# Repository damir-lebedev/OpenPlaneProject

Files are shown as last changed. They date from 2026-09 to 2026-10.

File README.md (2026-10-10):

<!-- i18n-bar:start -->
  <p align="center">
    🇷🇺 <b>Читать на русском</b>
    &nbsp;·&nbsp;
    <a href="docs/i18n/en/README.md">🇬🇧 Read this in English</a>
    &nbsp;·&nbsp;
    <a href="docs/i18n/zh-CN/README.md">🇨🇳 阅读中文版</a>
    &nbsp;·&nbsp;
    <a href="docs/i18n/es/README.md">🇪🇸 Lee esto en español</a>
  </p>
  <p align="center">
    <a href="docs/i18n/hi/README.md">🇮🇳 हिन्दी में पढ़ें</a>
    &nbsp;·&nbsp;
    <a href="docs/i18n/ar/README.md">🇸🇦 اقرأ بالعربية</a>
    &nbsp;·&nbsp;
    <a href="docs/i18n/pt-BR/README.md">🇧🇷 Leia em português</a>
    &nbsp;·&nbsp;
    <a href="docs/i18n/fr/README.md">🇫🇷 Lire en français</a>
  </p>
  <p align="center">
    <a href="docs/i18n/de/README.md">🇩🇪 Auf Deutsch lesen</a>
    &nbsp;·&nbsp;
    <a href="docs/i18n/ja/README.md">🇯🇵 日本語で読む</a>
    &nbsp;·&nbsp;
    <a href="docs/i18n/ko/README.md">🇰🇷 한국어로 읽기</a>
    &nbsp;·&nbsp;
    <a href="docs/i18n/sv/README.md">🇸🇪 Läs på svenska</a>
  </p>
<!-- i18n-bar:end -->

<p align="center">
  OpenPlane — открытый автопилот для самолётов
</p>

<p align="center">
  
  
  
  <br>
  
  
  
  
</p>

<h3 align="center">Выключили пульт — самолёт сам вернулся домой и кружит над вами.</h3>
<p align="center">Это не мультфильм: <b>вся прошивка</b> ведёт модель самолёта в замкнутом контуре — те же байты iBUS на входе, тот же ШИМ на выходе.</p>

<p align="center">
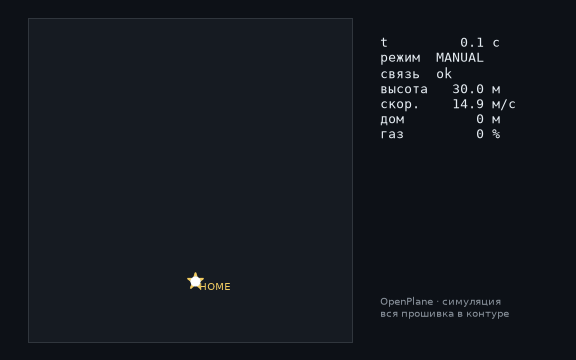
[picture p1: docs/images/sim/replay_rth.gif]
Потеря связи: самолёт сам возвращается домой и кружит
  
</p>

---

## ⚡ За 30 секунд

| | |
|---|---|
| **Что это** | Открытый полётный контроллер и автопилот для радиоуправляемых самолётов. Основная плата — STM32H743 (класс плат Pixhawk): на плате DevEBox прошивка **уже запущена и управляется с пульта** — [есть видео](#-stm32h743-ожила-на-плате), сейчас подключаются датчики. Прежняя основа — ESP32-S3 за ~$10, на ней пройден стенд со всеми датчиками. |
| **Что умеет** | 12 режимов полёта — от стабилизации до возврата домой, кругов по GPS, запуска с руки, автопосадки и **парения в термиках**. Трубка Пито из двух дешёвых барометров. Телеметрия MAVLink в QGroundControl и Mission Planner. |
| **Главная фишка** | Любой тумблер или крутилка пульта = любая функция. **Одна строка** в `Controls.h` — и SwD уже не RTH, а сброс груза. |
| **Почему можно верить** | 387 автотестов (плюс 9 на самой плате с настоящей SD-картой), 98 % кода под тестами, 24 сборки «плата × датчики» без единого предупреждения, замкнутые симуляции каждого режима. |
| **Честно** | В воздухе пока был ручной режим (первый прототип). STM32H743 пока проверена на столе, без датчиков. Автопилот проверен на стенде, тестами и симуляциями и ждёт лётных испытаний — [статус ниже](#-честный-статус). |

---

## 🎛️ Тумблер = функция. Одна строка.

```cpp
// include/config/Controls.h
constexpr Binding BINDINGS[] = {
    Bind::modes  (Channels::SWC, MODE_MANUAL, MODE_STABILIZE, MODE_AUTO_TAKEOFF),
    Bind::feature(Channels::SWB, Feature::FLAPS),
    Bind::mode   (Channels::SWD, MODE_RTH),              // домой, пока включён
    Bind::knob   (Channels::VRA, Knob::STAB_GAIN),       // "мягче / жёстче" прямо в полёте
    Bind::knob   (Channels::VRB, Knob::CRUISE_SPEED),
};
```

Хотите на SwD парение в термиках вместо RTH? `Bind::mode(Channels::SWD, MODE_SOARING)`. Сброс груза на SwB? `Bind::feature(Channels::SWB, Feature::PAYLOAD_DROP)`. Ошиблись — например, повесили два режима на один тумблер или заняли стик — **сборка не пройдёт**: таблицу проверяет компилятор (`static_assert`). При включении борт сам печатает, что на каком тумблере.

**12 режимов · 10 функций · 7 крутилок** — всё с примерами в [справочнике автопилота](docs/AUTOPILOT_GUIDE.md).

---

## ✈️ Что умеет автопилот

| | Режим | Суть |
|---|---|---|
| 🕹️ | **MANUAL** | рули = стики, как без полётника |
| 🧭 | **STABILIZE** | стик задаёт угол; отпустил — самолёт сам в горизонте |
| 📏 | **ALT_HOLD** | + держит высоту по барометру |
| 🌀 | **ACRO** | стик задаёт скорость вращения — для фигур |
| 🛣️ | **CRUISE** | курс, высота и скорость держатся сами; стики только поправляют |
| ⭕ | **LOITER** | круги над точкой по GPS (радиус — крутилкой) |
| 🏠 | **RTH** | домой на 40 м и круги над головой; сам включается при потере связи |
| 🛫 | **AUTO_TAKEOFF** | взлёт с полосы по газу пилота |
| 🤾 | **LAUNCH** | запуск с руки: мотор после броска, набор высоты |
| 🛬 | **AUTO_LAND** | планирование и выравнивание у земли |
| 🦅 | **SOARING** | мотор выключен, находит термики и кружит в них |
| 🆘 | **RESCUE** | «спасите»: крылья ровно, нос вверх — из любой спирали |

Плюс: геозабор, автотриммер «кривого» самолёта, координация разворота, защита от сваливания по трубке Пито, закрылки и воздушный тормоз, сброс груза, стабилизированная камера, пищалка «ищите меня в траве».

---

## 📈 Каждый режим летает — в замкнутом контуре

Не «функция вернула число», а **полёт**: пульт → кадр iBUS → прошивка → ШИМ → отклонения рулей → модель самолёта с подъёмной силой, сваливанием, ветром и термиками → датчики → снова прошивка. 14 таких полётов — часть обычных тестов (`pio test -e native`).

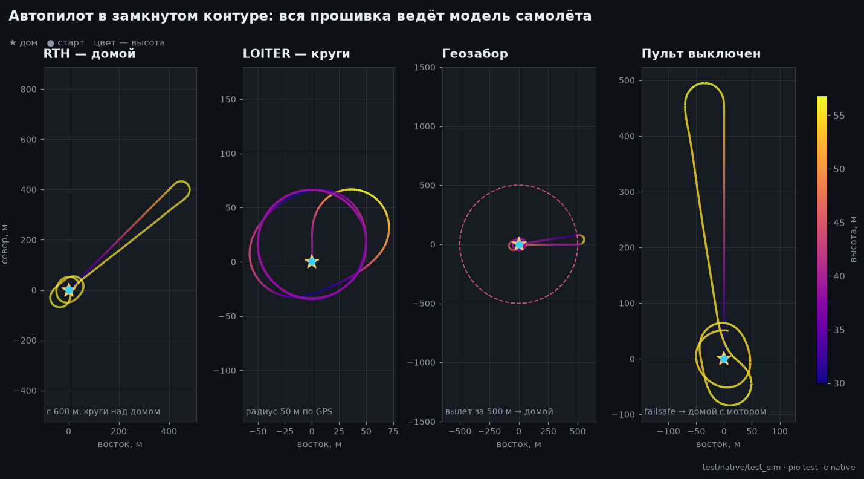
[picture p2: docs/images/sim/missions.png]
RTH, LOITER, геозабор и потеря связи — вид сверху


<table>
  <tr>
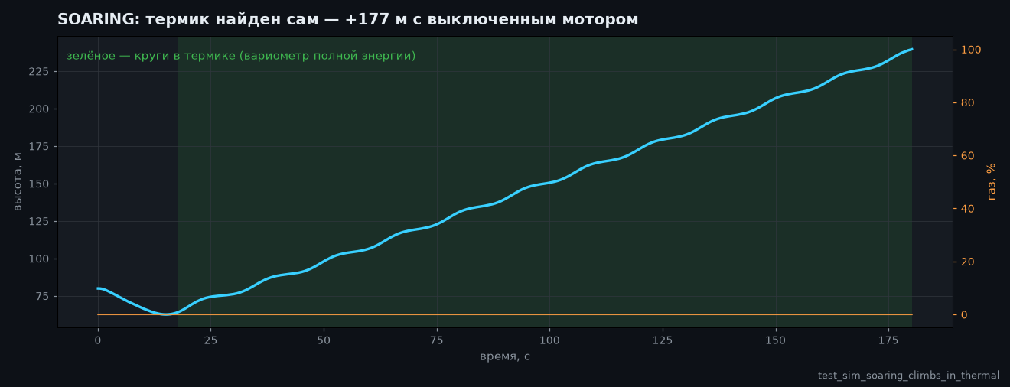
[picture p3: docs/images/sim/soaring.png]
Парение: набор высоты в термике без мотора
    <td width="50%"></td>
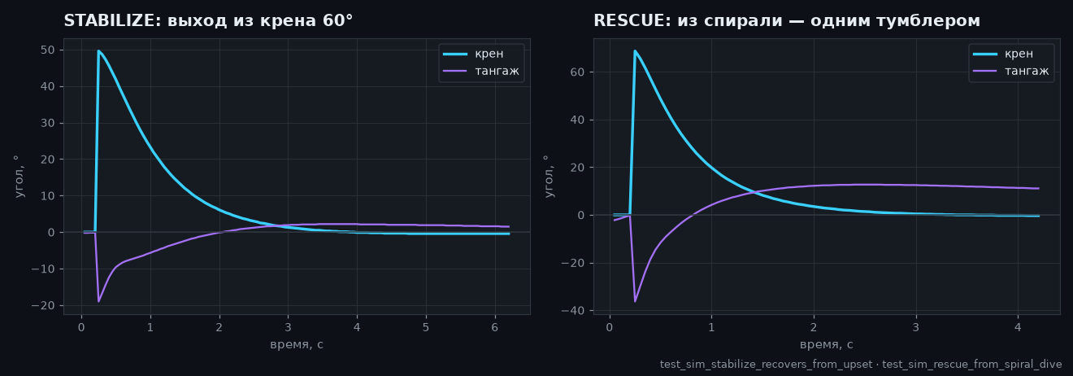
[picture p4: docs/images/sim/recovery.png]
Выход из крена и из спирали
    <td width="50%"></td>
  </tr>
  <tr>
    <td>🦅 Нашёл термик сам и набрал высоту <b>с выключенным мотором</b> — вариометр полной энергии не путает «ручку на себя» с восходящим потоком.</td>
    <td>🆘 Крен 60° — и через секунды горизонт. RESCUE вытаскивает из спирали с креном 70° и носом −40°.</td>
  </tr>
  <tr>
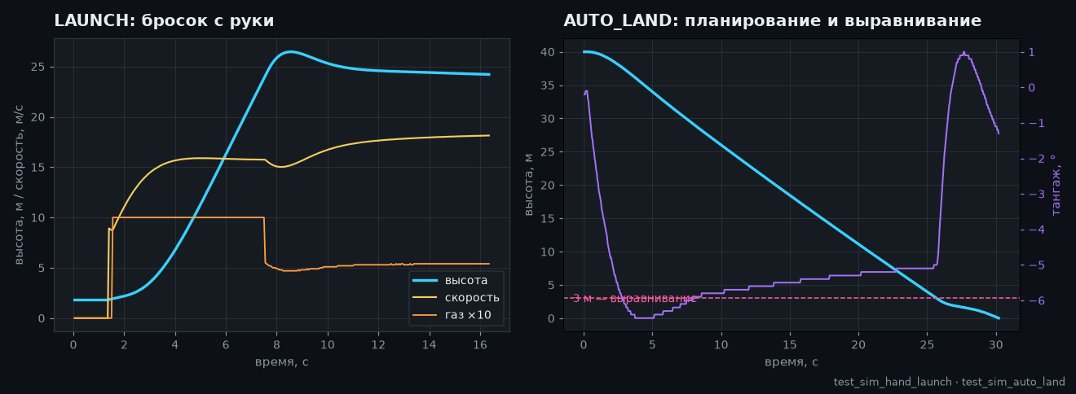
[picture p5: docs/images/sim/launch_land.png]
Запуск с руки и автопосадка
    <td></td>
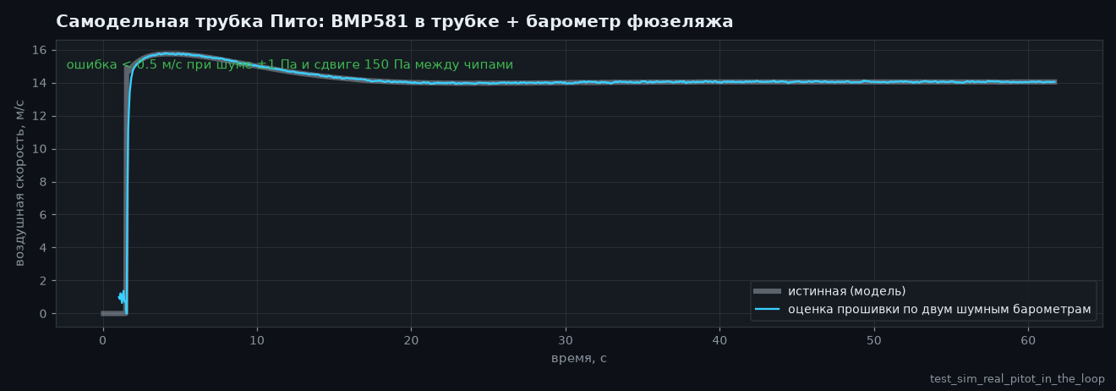
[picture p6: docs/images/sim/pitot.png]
Трубка Пито на двух барометрах
    <td></td>
  </tr>
  <tr>
    <td>🤾 Бросок с руки → мотор только после того, как рука ушла от винта → набор. 🛬 Посадка: планирование и выравнивание на 3 м.</td>
    <td>🌬️ Скорость по трубке из двух <b>шумных</b> барометров со сдвигом 150 Па между чипами — ошибка меньше 0.5 м/с.</td>
  </tr>
</table>

---

## 🌬️ Трубка Пито за копейки

Нормальный датчик воздушной скорости стоит как половина полётника. Здесь — **два барометра**: BMP581 в трубке (полное давление) и основной барометр в фюзеляже (статика). Прошивка сама обнуляет разницу чипов на земле, фильтрует, считает плотность воздуха по высоте и температуре и замечает перепутанные шланги. Что это даёт: CRUISE держит **воздушную** скорость, а не газ; защита от сваливания; честная скорость в телеметрии. Сборка — в [справочнике](docs/AUTOPILOT_GUIDE.md#трубка-пито-своими-руками).

---

## 📡 Наземная станция: браузер или QGroundControl

<table>
  <tr>
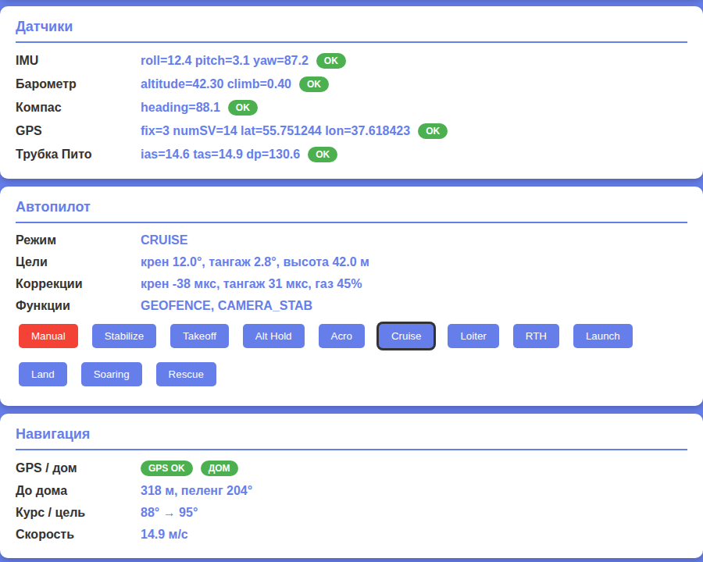
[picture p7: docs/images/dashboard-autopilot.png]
Веб-дашборд: датчики, автопилот, навигация
    <td width="46%"></td>
    <td>
      <b>ESP32 — веб-дашборд прямо с борта.</b> Точка доступа <code>OpenPlane-Debug</code>, адрес <code>192.168.4.1</code>: каналы пульта, выходы, все датчики, режим, навигация, смена режима и ПИД на лету. Без приложений и лишнего железа.<br><br>
      <b>STM32H743 — MAVLink по радиомодему.</b> QGroundControl и Mission Planner видят борт как самолёт ArduPilot: горизонт, карта с домом, скорость по трубке, режимы именами ArduPlane, ПИД из окна параметров, смена режима кнопкой. ARM с земли — нельзя, только тумблером: так безопаснее.<br><br>
      Кадры MAVLink побайтно сверены с эталонной <code>pymavlink</code>.
    </td>
  </tr>
</table>

---

## 📼 Чёрный ящик

Плата пишет каждый полёт: IMU на 500 Гц, углы и решения автопилота, ПИД, все выходы, стики, барометр, компас, GPS, батарея и события — с ARM и газа до посадки, с 10 секундами до старта. **ESP32-S3** — во встроенный флеш (13.9 МБ, около 11 минут), **STM32H743** — на SD-карту (64 МБ — около часа; карта остаётся обычной FAT32, прошивка пишет в заранее созданный файл `BLACKBOX.BIN`). Стирание — только на земле. После полёта `python tools/blackbox.py download` скачивает полёт по USB и раскладывает в CSV; с SD-карты полёты разбираются и без платы: `python tools/blackbox.py ring E:/BLACKBOX.BIN`. Подробно — [BLACKBOX.md](docs/BLACKBOX.md).

---

## 🔩 Железо: одна прошивка — четыре платы, двенадцать датчиков

| Плата | Статус | Что проверено |
|---|---|---|
| **STM32H743VIT6** | ✅ основная · 🔧 DevEBox, датчики подключаются + 🧪 тесты | на плате: загрузка, консоль по USB, **SD-карта и чёрный ящик** (тесты на плате), **приём iBUS, ARM и управление сервами и мотором с пульта** (запуск на видео); на ПК — вся прошивка: задачи FreeRTOS, флеш, MAVLink, I2C и SPI. Датчики к плате ещё не подключали |
| **ESP32-S3 N16R8** | ✅ прежняя основная, на стенде | все датчики, сервы, iBUS, OLED, дашборд вживую; прошивка целиком — в тестах |
| **ESP32 38-pin** | 🧪 тесты | прошивка целиком в тестах с набором ICM-45686 |
| **ESP32-C3 SuperMini** | ✈️ летал (ручной) | первый прототип; сборка всех наборов |

| Датчик | Что это | Шины |
|---|---|---|
| **LSM6DSV** + **QMC6309** | IMU + компас (модуль) | I2C / SPI |
| **ICM-45686** + **QMC6309** | IMU + компас (замена) | I2C / SPI |
| **SPL06-001** | барометр фюзеляжа | I2C / SPI |
| **BMP581** | основной барометр и барометр в трубке Пито | I2C / SPI |
| MPU6050/6500, ICM-42688, BMP388, BME280, QMC5883P/L | стендовые и прежние | I2C / SPI |
| **u-blox M10** | GPS, 10 Гц, UBX | UART |

Датчик меняется одной строкой (`SENSOR_KIT_LSM6DSV_PITOT`), плата — одним флагом сборки. Все 4 платы × 6 наборов датчиков собираются без предупреждений: [`tools/build_matrix.sh`](tools/build_matrix.sh).

<table>
  <tr>
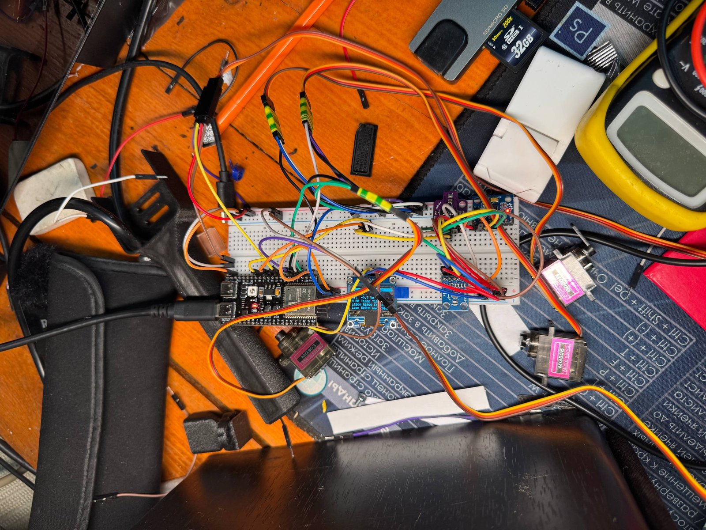
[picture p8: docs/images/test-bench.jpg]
Стенд: ESP32-S3 со всеми датчиками
    <td width="50%"></td>
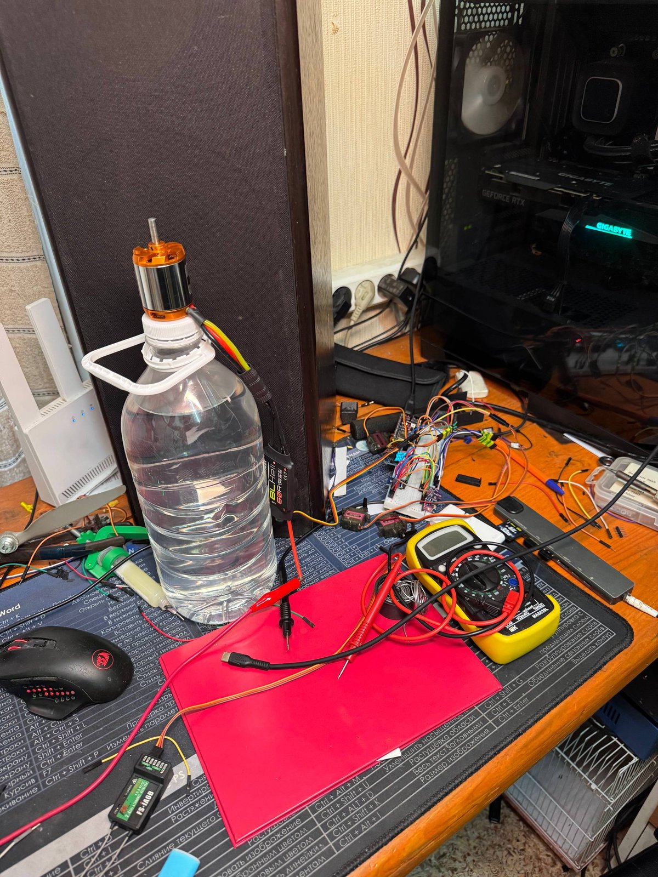
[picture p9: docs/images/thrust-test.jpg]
Тест тяги мотора
    <td width="50%"></td>
  </tr>
  <tr>
    <td>Стенд на ESP32-S3: IMU, барометр, компас, OLED, сервы, приёмник.</td>
    <td>Тест винтомоторной группы.</td>
  </tr>
</table>

### 🎥 STM32H743 ожила на плате

Прошивка для STM32H743 запущена на плате DevEBox **без единого датчика** и управляется с обычного пульта: приёмник по iBUS, ARM, сервы и мотор отвечают на стики и тумблеры в ручном режиме. Весь запуск снят на видео.

▶️ **[Смотреть запуск на видео](https://t.me/lisnmylife/420)**

Что это доказывает: тракт «пульт → iBUS → прошивка → ШИМ» работает на настоящем железе, а не только в тестах. Что ещё не доказано: датчики (IMU, барометр, GPS) к этой плате не подключали, поэтому режимы автопилота на ней пока не пробовались.

---

## 🧪 Качество, которое можно проверить

| | |
|---|---|
| **387 автотестов** | модули, драйверы по регистрам чипов, замкнутые полёты, прошивка ESP32 и STM32 **целиком** на ПК; плюс 9 тестов на самой плате STM32 с настоящей SD-картой |
| **98.3 % строк, 87.7 % ветвлений** | покрытие `gcovr`, включая код STM32 |
| **24/24 сборки** | 4 платы × 6 наборов датчиков, `-Wall -Wextra`, ноль предупреждений |
| **0 замечаний** | cppcheck и clang-tidy по всему коду |
| **Эталоны, а не копии кода** | формулы датчиков — по датащитам (Bosch, ST, TDK, Goertek), MAVLink — по pymavlink |

```bash
pio test -e native -e native-stm32   # все тесты, ~1.5 минуты, железо не нужно
```

Подробно — [TESTING.md](docs/TESTING.md).

---

## 🧠 Как устроено

```mermaid
flowchart LR
    RC["Пульт FS-i6<br/>iBUS"] --> SW["PilotSwitches<br/>Controls.h"]
    SENS["IMU · барометры · компас<br/>GPS · трубка Пито"] --> AP
    SW --> AP["Autopilot<br/>12 режимов · навигация<br/>failsafe · геозабор"]
    AP --> FC["FlightController<br/>ARM · микшер · закрылки"]
    FC --> OUT["Сервы · ESC<br/>груз · камера"]
    AP -.-> TLM["Дашборд Wi-Fi<br/>MAVLink · OLED"]
```

- **Header-only C++**, одна единица трансляции, никакой динамической памяти в полётном контуре. Любитель `.h/.cpp`? Для вас — параллельная ветка [`feature/split-headers`](https://github.com/damir-lebedev/OpenPlaneProject/tree/feature/split-headers): генерируется из этой скриптом, прошивка с LTO того же размера.
- **HAL** — единственный слой, знающий MCU: новая плата — это новый `Board`, а не переписанный автопилот.
- **Драйвер датчика не знает шину**: один класс работает по I2C и по SPI.
- **Безопасность — порядком операций**: потеря связи > ARM > режим > газ; ни один режим не протащит газ мимо ARM.

Подробно — [ARCHITECTURE.md](docs/ARCHITECTURE.md).

---

## 🚀 Быстрый старт

```bash
pip install platformio
git clone https://github.com/damir-lebedev/OpenPlaneProject && cd OpenPlaneProject
pio run -e stm32h743-devebox -t upload                    # DevEBox H743: USB DFU, консоль по USB
pio run -e esp32-s3 -t upload && pio device monitor     # ESP32-S3
pio run -e stm32h743 -t upload                            # STM32H743 (ST-Link)
```

DevEBox: на плате нет кнопки BOOT0 — перед первой заливкой соедините пин BT0 с 3V3 и нажмите RST; потом клавиша `D` в консоли сама перезагружает плату в загрузчик ([подробно](docs/DEVELOPER_GUIDE.md#stm32h743)).

В мониторе порта: `h` — меню, `b` — какие чипы видны на шинах, `s` — датчики, `p` — проверка выходов (пропеллер снять!). Дальше — [гайд пилота](docs/PILOT_GUIDE.md).

---

## 🟢 Честный статус

| Что | Где проверено |
|---|---|
| Ручное управление, микшер | ✈️ в полёте (первый прототип, C3) |
| ARM, failsafe, закрылки, сервы, мотор | 🔧 на стенде (S3) |
| STABILIZE | 🔧 на стенде: рули отвечают на наклоны в правильную сторону |
| Датчики стенда (MPU6500, BMP388, QMC5883P), OLED, дашборд | 🔧 на стенде |
| Остальные режимы, навигация, трубка Пито, MAVLink | 🧪 тесты и замкнутые симуляции |
| Новые датчики (LSM6DSV, ICM-45686, QMC6309, SPL06, BMP581) | 🧪 регистровые эмуляторы по датащитам |
| STM32H743: SD-карта, чёрный ящик, консоль по USB | 🔧 на плате DevEBox (тесты на плате) |
| STM32H743: iBUS, ARM, ШИМ на серво и мотор, ручное управление | 🔧 на плате без датчиков, снято на видео |
| STM32H743: датчики (IMU, барометр, компас, GPS) и режимы автопилота | 🧪 вся прошивка на ПК; к плате датчики ещё не подключали |

Модель самолёта в симуляциях упрощённая, коэффициенты — стартовые. Каждый новый режим сначала пробуется на высоте, с пальцем на тумблере MANUAL.

---

## 🗺️ Дорожная карта

- [x] Ручное управление, ARM, failsafe, объектная прошивка, веб-дашборд
- [x] Стенд ESP32-S3 со всеми датчиками — вживую
- [x] 12 режимов, навигация по GPS, RTH при потере связи, геозабор
- [x] Тумблеры и крутилки одной строкой, сброс груза, камера, автотриммер
- [x] Трубка Пито из двух барометров, защита от сваливания
- [x] Новые датчики: LSM6DSV, ICM-45686, QMC6309, SPL06, BMP581
- [x] STM32H743: полная прошивка, MAVLink, настройки во флеше
- [x] Замкнутые симуляции всех режимов, прошивка целиком в тестах
- [x] Чёрный ящик: полёт во флеш (ESP32-S3) и на SD-карту (STM32H743), выгрузка и разбор в CSV
- [x] STM32H743 запущена на плате: пульт → iBUS → сервы и мотор (без датчиков, на видео)
- [ ] STM32H743: подключить датчики и пройти стенд так же, как ESP32-S3
- [ ] Лётные испытания автопилота на новом планере
- [ ] Своя плата полётника ([FC_BOARD.md](docs/FC_BOARD.md)) на STM32H743
- [ ] Полёт по маршрутным точкам, миссии MAVLink
- [ ] Адаптивная обратная связь (заготовка уже проверена в симуляции)
- [ ] Датчик тока и батареи, телеметрия на пульт (iBUS-SENS)
- [ ] Автономная доставка: маршрут → сброс груза → домой

Подробно — [ROADMAP.md](docs/ROADMAP.md).

---

## 💼 Для партнёров и инвесторов

Небольшие самолёты-доставщики и мониторинговые борта — это либо закрытые дорогие платформы, либо разрозненные хобби-проекты. OpenPlane целится в середину: **открытый, проверяемый автопилот на массовом железе**, где каждая функция покрыта тестами и может быть адаптирована под задачу — доставка медикаментов в труднодоступные места, мониторинг полей и лесов, поисковые работы.

Что уже сделано на свои: архитектура, которая переносится между платами без переписывания; автопилот с полным набором режимов; инфраструктура тестов, на которой новые функции появляются быстро и не ломают старые. Что ускорят ресурсы: лётные испытания, своя плата полётника на STM32H743, полёт по маршруту и сброс груза. Куда и зачем — [ROADMAP.md](docs/ROADMAP.md).

---

## 📚 Документация

| Документ | Для кого |
|---|---|
| [AUTOPILOT_GUIDE.md](docs/AUTOPILOT_GUIDE.md) | пилоту: каждый режим, функция и крутилка, как повесить на тумблер, трубка Пито, наземная станция |
| [PILOT_GUIDE.md](docs/PILOT_GUIDE.md) | сборка, распиновка, пульт, failsafe, первый полёт |
| [DEVELOPER_GUIDE.md](docs/DEVELOPER_GUIDE.md) | разработчику: файлы, знаки, API, как добавить датчик, режим, плату |
| [ARCHITECTURE.md](docs/ARCHITECTURE.md) | слои, задачи, такт управления, автоматы |
| [TESTING.md](docs/TESTING.md) | тесты, симуляции, покрытие, анализ |
| [reference/](docs/reference/README.md) | справочник по каждому классу |
| [FC_BOARD.md](docs/FC_BOARD.md) · [ROADMAP.md](docs/ROADMAP.md) | плата полётника · куда движется проект |
| [airframe/](airframe/README.md) | планер Astro-Cargo: проект Fusion 360 и STL для печати, известные недостатки версии v2 |

> **Связанный проект:** [esp32-rc-joystick](https://github.com/damir-lebedev/esp32-rc-joystick) — пульт FS-i6 как USB-джойстик для симулятора на той же ESP32-S3: сначала налетать часы в симуляторе, потом — в поле.

---

## 🤝 Участие

Нужны руки и головы: аэродинамика и авиамоделизм, 3D-печать и прочность, встраиваемый C++, датчики и автопилоты, наземные интерфейсы. Issues и pull request'ы — в ветку `main`; начать — с [DEVELOPER_GUIDE.md](docs/DEVELOPER_GUIDE.md).

## 📜 Лицензия

[OpenPlane License](LICENSE) — лицензия на основе MIT с дополнительными условиями. Код, документацию и файлы модели можно использовать, копировать, менять и продавать, в том числе в коммерческих продуктах. Условия такие:

1. **Укажите автора — Damir Lebedev (Damn / Проклятый).** Имя должно стоять там, где его увидят пользователи вашего продукта: в документации, README или на странице «О проекте». Текст лицензии оставляйте вместе с кодом.
2. **Военное применение запрещено.** Нельзя использовать проект для армий и военизированных организаций, на войне, при создании оружия, боеприпасов, систем доставки и наведения.
3. **Нельзя намеренно вредить людям и имуществу без их предварительного письменного согласия на этот вред.** Свою собственную технику ломать можно, если это никому не угрожает: например, стрелять из пневматического пистолета по собственному дрону. Калечить и убивать людей нельзя.
4. **Соблюдайте технику безопасности и законы** при сборке, испытаниях и полётах.

Если условия нарушены, разрешение на использование прекращается. Из-за запретов на отдельные виды использования это не «открытая» лицензия в понимании OSI: код доступен для чтения, копирования и изменения, но формально проект относится к source-available, а не к open source.

Юридическую силу имеет только английский текст в файле [LICENSE](LICENSE): переводы лицензии на другие языки даны для удобства.

Прошивка управляет летательным аппаратом и не сертифицирована. Всё, что вы с ней делаете, — на ваш страх и риск; автор ответственности не несёт.

```text
OpenPlane © 2026 Damir Lebedev (Damn / Проклятый) — https://github.com/damir-lebedev/OpenPlaneProject
```

<p align="center"><i>Первый прототип сломался в первом же полёте — поэтому здесь всё на виду: код, тесты, проблемы. Собирайте, ломайте, чините вместе с нами.</i></p>

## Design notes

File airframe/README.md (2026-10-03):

# Планер Astro-Cargo: модель и файлы для печати

Здесь лежит сам самолёт: проект в Fusion 360 и STL-файлы для 3D-печати. Электронику и плату полётника описывает [FC_BOARD.md](../docs/FC_BOARD.md), а сборку и первый полёт — [гайд пилота](../docs/PILOT_GUIDE.md).

## Версия модели: v2

В этой папке лежит **Astro-Cargo v2**. Версии v1 в репозитории не будет: первая модель не публикуется, поэтому вторая стала первой выложенной.

- [Проект Fusion 360](fusion360/Astro-Cargo%20v2%20%28Bad%20wheel%20%26%20no%20battery%20mount%29.f3d), 14 МБ;
- [STL-файл для печати](stl/Astro-Cargo%20v2%20%28Bad%20wheel%20%26%20no%20battery%20mount%29.stl), 6 МБ.

Файлы названы так, чтобы по имени было сразу видно, что в этой версии не так (подробности ниже).

> [!WARNING]
> **В v2 найдены критические недостатки конструкции:**
>
> 1. **Слабое крепление шасси к фюзеляжу.** Оно не выдерживает вес самолёта, и фюзеляж рвётся в месте крепления.
> 2. **Нет крепления для ленты-липучки (велкро), которой фиксируется аккумулятор.**
>
> Оба недостатка будут исправлены в следующем прототипе, **Astro-Cargo v3**. Его модель появится в этой папке, как только будет готова. До тех пор не поднимайте v2 в воздух без доработки: усильте крепление шасси и сделайте место под липучку сами.

## Что где лежит

| Папка | Что в ней |
|---|---|
| [`fusion360/`](fusion360/) | Исходный проект: файл `.f3d` (или архив `.f3z`, если в проекте несколько файлов). Из него можно менять размеры и заново выгружать детали |
| [`stl/`](stl/) | Детали, готовые к печати, в формате STL |

## Как называть файлы

- Имена — латиницей, с номером версии. Файлы v2 названы так, чтобы имя говорило о недостатках, но дальше лучше обходиться без пробелов и скобок: `astro-cargo_v3.f3d`, `astro-cargo_v3.stl`. Так на файл проще ссылаться из документации. Если деталей несколько, то каждая лежит в своём файле: `fuselage_v3.stl`, `wing_left_v3.stl`.
- Файлы v3 будут лежать рядом (`astro-cargo_v3.f3d`), а файлы v2 останутся: по ним видно, что именно исправлено.
- Единицы — миллиметры. Если в проекте другие, напишите об этом рядом с файлом.

## Если файл слишком большой

GitHub не принимает файлы тяжелее 100 МБ, а предупреждает уже начиная с 50 МБ. Поэтому перед коммитом проверьте размер файла. Такие файлы кладите не в репозиторий, а:

- в раздел **Releases** на GitHub: файл можно прикрепить к релизу, и он может весить до 2 ГБ;
- в [Git LFS](https://git-lfs.com), если файл должен лежать прямо в репозитории и меняться вместе с кодом;
- на внешний хостинг, а ссылку на него добавьте в этот README.

Файлы `.stl`, `.f3d`, `.f3z`, `.step`, `.stp` и `.3mf` в этой папке git считает бинарными (см. [`.gitattributes`](../.gitattributes)): он не меняет в них переводы строк и не показывает построчные различия.

## Лицензия

Модель распространяется на тех же условиях, что и весь проект: [OpenPlane License](../LICENSE), то есть MIT с обязательным указанием автора, запретом военного применения и запретом умышленного вреда людям и имуществу без их согласия. Печатать, менять и улучшать её можно в этих рамках, но имя автора, Damir Lebedev (Damn / Проклятый), нужно указать.

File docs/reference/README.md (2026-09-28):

# Справочник по классам

Полный перечень классов, структур, перечислений и пространств имён прошивки,
сгруппированный по слоям. Общая картина (слои, потоки, автоматы) — в
[`../ARCHITECTURE.md`](../ARCHITECTURE.md); практические рецепты — в
[`../DEVELOPER_GUIDE.md`](../DEVELOPER_GUIDE.md).

Все пути — от `include/`, кроме `src/`. Все классы header-only (вариант с `.h/.cpp` — ветка `feature/split-headers`).

| Страница | Слой | Что внутри |
|---|---|---|
| [config.md](config.md) | CONFIG | `Config`, `Channels`, `Controls` |
| [hal.md](hal.md) | HAL | `IBoard`, `ServoChannel`, `II2CBus`, `ISpiBus`, `IUartPort`, `IServoOutput`, `IRegisterDevice`, `I2cRegisterDevice`, `SpiRegisterDevice`, `Rtos`, `Esp32Board`, `Esp32I2CBus`, `Esp32SpiBus`, `Esp32UartPort`, `Esp32ServoOutput`; STM32H743: `Stm32Board`, `Stm32I2CBus`, `Stm32SpiBus`, `Stm32UartPort`, `Stm32ServoOutput`, `Stm32FlashStorage`, `compat/Preferences` |
| [storage.md](storage.md) | STORAGE | `IFlashStorage`, `KeyValueStore`, `KvPreferences` |
| [rc.md](rc.md) | RC | `RcChannelState`, `RcInput`, `IBusReceiver` |
| [control.md](control.md) | CONTROL / COORDINATION | `ControlCommand`, `FlightOutputState`, `FlapsController`, `ControlMixer`, `ThrottleManager`, `ArmingManager`, `FlightOutputs`, `Beeper`, `FlightController` |
| [autopilot.md](autopilot.md) | AUTOPILOT | `AutopilotMode`, `Feature`, `Knob`, `PilotInputs`, `Binding`/`Bind`/`BindingCheck`, `PilotSwitches`, `Autopilot`, `NavStatus`, `Geo`/`Guidance`, `AltitudeSpeedController`, `LaunchController`, `SoaringController`, `AutoTrim`, `PidController` |
| [feedback.md](feedback.md) | AUTOPILOT / feedback | `FeedbackConfig`, `FeedbackMath`, `FlightSnapshot`, `FeedbackOutput`, `PhaseTargets`, `SpeedEstimator`, `AirborneDetector`, `ControlEffectivenessEstimator`, `AxisModel`, `AdaptiveRateController`, `StallGuard`, `TakeoffSequencer`, `LandingSequencer`, `FeedbackSupervisor` |
| [sensors.md](sensors.md) | SENSORS | интерфейсы и данные, `SensorMounting`, `SensorSelection`, `ImuOrientation`, `AttitudeEstimator`, `ImuSensorBase`, `MPU6050_Sensor`, `ICM42688_Sensor`, `LSM6DSV_Sensor`, `ICM45686_Sensor`, `BarometerBase`, `BMP388_Sensor`, `BME280_Sensor`, `SPL06_Sensor`, `BMP581_Sensor`, `MagnetometerBase`, `QMC5883P_Sensor`, `QMC5883L_Sensor`, `QMC6309_Sensor`, `UbloxM10_Gps`, `AirspeedSensor`, `PitotDualBaroAirspeed` |
| [telemetry.md](telemetry.md) | TELEMETRY | `LoopStats`, `LogChannel`, `LogMode`, `LogSettings`, `DebugLogger`, `DebugConsole`, `WebDashboardPage`, `WebDebugServer`, `OledDisplay`, `Mavlink` (кодек), `MavlinkModes`, `MavlinkTelemetry` |
| [application.md](application.md) | APPLICATION | `src/main.cpp` (ESP32) и `src/stm32/main.cpp` (STM32H743): глобальные объекты, `setup()`, цикл и задачи |

## Алфавитный указатель

| Сущность | Вид | Файл | Страница |
|---|---|---|---|
| `AdaptiveRateController` | class | `autopilot/feedback/AdaptiveRateController.h` | [feedback](feedback.md#adaptiveratecontroller) |
| `AirborneDetector` | class | `autopilot/feedback/AirborneDetector.h` | [feedback](feedback.md#airbornedetector) |
| `AirspeedData`, `AirspeedSensor` | struct, interface | `sensors/airspeed/AirspeedSensor.h` | [sensors](sensors.md#airspeedsensor) |
| `AltitudeSpeedController` | class | `autopilot/AltitudeSpeedController.h` | [autopilot](autopilot.md#altitudespeedcontroller) |
| `ArmingManager` | class | `control/ArmingManager.h` | [control](control.md#armingmanager) |
| `AttitudeEstimator` | class | `sensors/imu/AttitudeEstimator.h` | [sensors](sensors.md#attitudeestimator) |
| `Autopilot` | class | `autopilot/Autopilot.h` | [autopilot](autopilot.md#autopilot) |
| `AutopilotMode` | enum | `autopilot/AutopilotTypes.h` | [autopilot](autopilot.md#autopilotmode-feature-knob) |
| `AutoTrim` | class | `autopilot/AutoTrim.h` | [autopilot](autopilot.md#autotrim) |
| `AxisModel` | struct | `autopilot/feedback/AdaptiveRateController.h` | [feedback](feedback.md#axismodel) |
| `BarometerBase` | abstract class | `sensors/baro/BarometerBase.h` | [sensors](sensors.md#barometerbase) |
| `BarometerData`, `BarometerSensor` | struct, interface | `sensors/SensorInterface.h` | [sensors](sensors.md#интерфейсы-и-структуры-данных) |
| `Beeper` | class | `control/Beeper.h` | [control](control.md#beeper) |
| `Binding`, `Bind`, `BindingCheck` | struct, namespace | `autopilot/ControlBinding.h` | [autopilot](autopilot.md#binding-bind-bindingcheck) |
| `BME280_Sensor` | class | `sensors/baro/BME280_Sensor.h` | [sensors](sensors.md#bme280_sensor) |
| `BMP388_Sensor` | class | `sensors/baro/BMP388_Sensor.h` | [sensors](sensors.md#bmp388_sensor) |
| `BMP581_Sensor` | class | `sensors/baro/BMP581_Sensor.h` | [sensors](sensors.md#bmp581_sensor) |
| `Channels` | namespace | `config/Channels.h` | [config](config.md#namespace-channels) |
| `Config` | namespace | `config/Config.h` | [config](config.md#namespace-config) |
| `ControlCommand` | struct | `control/ControlCommand.h` | [control](control.md#controlcommand) |
| `ControlEffectivenessEstimator` | class | `autopilot/feedback/ControlEffectivenessEstimator.h` | [feedback](feedback.md#controleffectivenessestimator) |
| `ControlMixer` | class | `control/ControlMixer.h` | [control](control.md#controlmixer) |
| `Controls` | namespace | `config/Controls.h` | [config](config.md#namespace-controls) |
| `DebugConsole` | class | `telemetry/DebugConsole.h` | [telemetry](telemetry.md#debugconsole) |
| `DebugLogger` | class | `telemetry/DebugLogger.h` | [telemetry](telemetry.md#debuglogger) |
| `Esp32Board` | class | `hal/esp32/Esp32Board.h` | [hal](hal.md#esp32board) |
| `Esp32I2CBus` | class | `hal/esp32/Esp32I2CBus.h` | [hal](hal.md#esp32i2cbus) |
| `Esp32ServoOutput` | class | `hal/esp32/Esp32ServoOutput.h` | [hal](hal.md#esp32servooutput) |
| `Esp32SpiBus` | class | `hal/esp32/Esp32SpiBus.h` | [hal](hal.md#esp32spibus) |
| `Esp32UartPort` | class | `hal/esp32/Esp32UartPort.h` | [hal](hal.md#esp32uartport) |
| `Feature`, `Knob`, `PilotInputs` | enum, struct | `autopilot/AutopilotTypes.h` | [autopilot](autopilot.md#autopilotmode-feature-knob) |
| `FeedbackConfig` | namespace | `autopilot/feedback/FeedbackConfig.h` | [feedback](feedback.md#namespace-feedbackconfig) |
| `FeedbackMath` | namespace | `autopilot/feedback/FeedbackMath.h` | [feedback](feedback.md#namespace-feedbackmath) |
| `FeedbackOutput` | struct | `autopilot/feedback/FeedbackOutput.h` | [feedback](feedback.md#feedbackoutput) |
| `FeedbackSupervisor` | class | `autopilot/feedback/FeedbackSupervisor.h` | [feedback](feedback.md#feedbacksupervisor) |
| `FlapsController` | class | `control/FlapsController.h` | [control](control.md#flapscontroller) |
| `FlightController` | class | `control/FlightController.h` | [control](control.md#flightcontroller) |
| `FlightOutputs`, `FlightOutputs::OutputInfo` | class, struct | `control/FlightOutputs.h` | [control](control.md#flightoutputs) |
| `FlightOutputState` | struct | `control/FlightOutputState.h` | [control](control.md#flightoutputstate) |
| `FlightSnapshot` | struct | `autopilot/feedback/FlightSnapshot.h` | [feedback](feedback.md#flightsnapshot) |
| `Geo`, `Guidance`, `GeoPoint` | namespace, struct | `autopilot/Navigation.h` | [autopilot](autopilot.md#geo-guidance-geopoint) |
| `GpsData`, `GpsSensor` | struct, interface | `sensors/SensorInterface.h` | [sensors](sensors.md#интерфейсы-и-структуры-данных) |
| `I2cRegisterDevice` | class | `hal/RegisterDevice.h` | [hal](hal.md#i2cregisterdevice) |
| `IBoard` | interface | `hal/IBoard.h` | [hal](hal.md#iboard) |
| `IBusReceiver` | class | `rc/IBusReceiver.h` | [rc](rc.md#ibusreceiver) |
| `ICM42688_Sensor` | class | `sensors/imu/ICM42688_Sensor.h` | [sensors](sensors.md#icm42688_sensor) |
| `ICM45686_Sensor` | class | `sensors/imu/ICM45686_Sensor.h` | [sensors](sensors.md#icm45686_sensor) |
| `IFlashStorage` | interface | `storage/KeyValueStore.h` | [storage](storage.md#iflashstorage) |
| `II2CBus` | interface | `hal/II2CBus.h` | [hal](hal.md#ii2cbus) |
| `ImuData`, `ImuSensor` | struct, interface | `sensors/SensorInterface.h` | [sensors](sensors.md#интерфейсы-и-структуры-данных) |
| `ImuOrientation` | class | `sensors/imu/ImuOrientation.h` | [sensors](sensors.md#imuorientation) |
| `ImuSensorBase` | abstract class | `sensors/imu/ImuSensorBase.h` | [sensors](sensors.md#imusensorbase) |
| `IRegisterDevice` | interface | `hal/RegisterDevice.h` | [hal](hal.md#iregisterdevice) |
| `IServoOutput` | interface | `hal/IServoOutput.h` | [hal](hal.md#iservooutput) |
| `ISpiBus` | interface | `hal/ISpiBus.h` | [hal](hal.md#ispibus) |
| `IUartPort` | interface | `hal/IUartPort.h` | [hal](hal.md#iuartport) |
| `KeyValueStore` | class | `storage/KeyValueStore.h` | [storage](storage.md#keyvaluestore) |
| `KvPreferences` | class | `storage/KvPreferences.h` | [storage](storage.md#kvpreferences) |
| `LandingSequencer` | class | `autopilot/feedback/LandingSequencer.h` | [feedback](feedback.md#landingsequencer) |
| `LaunchController` | class | `autopilot/LaunchController.h` | [autopilot](autopilot.md#launchcontroller) |
| `LogChannel`, `LogMode`, `LogChannelInfo` | enum, enum, struct | `telemetry/LogSettings.h` | [telemetry](telemetry.md#logsettings) |
| `LogSettings` | class | `telemetry/LogSettings.h` | [telemetry](telemetry.md#logsettings) |
| `LoopStats` | struct | `telemetry/LoopStats.h` | [telemetry](telemetry.md#loopstats) |
| `LSM6DSV_Sensor` | class | `sensors/imu/LSM6DSV_Sensor.h` | [sensors](sensors.md#lsm6dsv_sensor) |
| `MagData`, `MagnetometerSensor` | struct, interface | `sensors/SensorInterface.h` | [sensors](sensors.md#интерфейсы-и-структуры-данных) |
| `MagnetometerBase` | abstract class | `sensors/mag/MagnetometerBase.h` | [sensors](sensors.md#magnetometerbase) |
| `Mavlink` | namespace | `telemetry/MavlinkCodec.h` | [telemetry](telemetry.md#mavlink-кодек) |
| `MavlinkModes`, `MavlinkTelemetry` | namespace, class | `telemetry/MavlinkTelemetry.h` | [telemetry](telemetry.md#mavlinktelemetry) |
| `MPU6050_Sensor` | class | `sensors/imu/MPU6050_Sensor.h` | [sensors](sensors.md#mpu6050_sensor) |
| `OledDisplay` | class | `telemetry/OledDisplay.h` | [telemetry](telemetry.md#oleddisplay) |
| `PhaseTargets` | struct | `autopilot/feedback/PhaseTargets.h` | [feedback](feedback.md#phasetargets) |
| `PidController` | class | `autopilot/PidController.h` | [autopilot](autopilot.md#pidcontroller) |
| `PilotSwitches` | class | `autopilot/PilotSwitches.h` | [autopilot](autopilot.md#pilotswitches) |
| `PitotDualBaroAirspeed` | class | `sensors/airspeed/PitotDualBaroAirspeed.h` | [sensors](sensors.md#pitotdualbaroairspeed) |
| `QMC5883L_Sensor` | class | `sensors/mag/QMC5883L_Sensor.h` | [sensors](sensors.md#qmc5883l_sensor) |
| `QMC5883P_Sensor` | class | `sensors/mag/QMC5883P_Sensor.h` | [sensors](sensors.md#qmc5883p_sensor) |
| `QMC6309_Sensor` | class | `sensors/mag/QMC6309_Sensor.h` | [sensors](sensors.md#qmc6309_sensor) |
| `RawImuSample` | struct | `sensors/imu/ImuSensorBase.h` | [sensors](sensors.md#imusensorbase) |
| `RcChannelState` | class | `rc/RcChannelState.h` | [rc](rc.md#rcchannelstate) |
| `RcInput` | class (static) | `rc/RcInput.h` | [rc](rc.md#rcinput) |
| `Rtos` | namespace | `hal/Rtos.h` | [hal](hal.md#rtos) |
| `Sensor` | interface | `sensors/SensorInterface.h` | [sensors](sensors.md#интерфейсы-и-структуры-данных) |
| `SensorMounting` | namespace | `sensors/SensorMounting.h` | [sensors](sensors.md#namespace-sensormounting) |
| `SensorSelection.h` | макросы | `sensors/SensorSelection.h` | [sensors](sensors.md#sensorselectionh) |
| `ServoChannel` | namespace | `hal/IBoard.h` | [hal](hal.md#namespace-servochannel) |
| `SoaringController` | class | `autopilot/SoaringController.h` | [autopilot](autopilot.md#soaringcontroller) |
| `SpeedEstimator` | class | `autopilot/feedback/SpeedEstimator.h` | [feedback](feedback.md#speedestimator) |
| `SpiRegisterDevice` | class | `hal/RegisterDevice.h` | [hal](hal.md#spiregisterdevice) |
| `SPL06_Sensor` | class | `sensors/baro/SPL06_Sensor.h` | [sensors](sensors.md#spl06_sensor) |
| `StallGuard` | class | `autopilot/feedback/StallGuard.h` | [feedback](feedback.md#stallguard) |
| `Stm32Board` | class | `hal/stm32/Stm32Board.h` | [hal](hal.md#stm32board) |
| `Stm32FlashStorage` | class | `hal/stm32/Stm32FlashStorage.h` | [hal](hal.md#stm32flashstorage) |
| `Stm32I2CBus` | class | `hal/stm32/Stm32I2CBus.h` | [hal](hal.md#stm32i2cbus) |
| `Stm32ServoOutput` | class | `hal/stm32/Stm32ServoOutput.h` | [hal](hal.md#stm32servooutput) |
| `Stm32SpiBus` | class | `hal/stm32/Stm32SpiBus.h` | [hal](hal.md#stm32spibus) |
| `Stm32UartPort` | class | `hal/stm32/Stm32UartPort.h` | [hal](hal.md#stm32uartport) |
| `TakeoffSequencer` | class | `autopilot/feedback/TakeoffSequencer.h` | [feedback](feedback.md#takeoffsequencer) |
| `ThrottleManager` | class | `control/ThrottleManager.h` | [control](control.md#throttlemanager) |
| `UbloxM10_Gps` | class | `sensors/gps/UbloxM10_Gps.h` | [sensors](sensors.md#ubloxm10_gps) |
| `WebDashboardPage` | namespace | `telemetry/WebDashboardPage.h` | [telemetry](telemetry.md#webdashboardpage) |
| `WebDebugServer` | class | `telemetry/WebDebugServer.h` | [telemetry](telemetry.md#webdebugserver) |

## Условные обозначения

- **Единицы:** мкс — микросекунды PWM или отклонения (±500 = полный ход);
  °, °/с, °/с² — углы и их производные в авиационных знаках (крен + правое
  крыло вниз, тангаж + нос вверх, рысканье + нос вправо); g — ускорение
  в долях g; оси самолёта: X к носу, Y влево, Z вверх.
- **Время:** `millis()`/`micros()` — `uint32_t`; все разности времени
  считаются беззнаковым вычитанием и корректно переживают переполнение
  (≈49.7 суток для `millis()`, ≈71.6 минуты для `micros()`).
- **«Заготовка»** — код есть и проверен тестами, но в прошивку не подключён.

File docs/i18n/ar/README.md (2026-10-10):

<!-- i18n-bar:start -->
  <p align="center">
    <a href="../../../README.md">🇷🇺 Читать на русском</a>
    &nbsp;·&nbsp;
    <a href="../en/README.md">🇬🇧 Read this in English</a>
    &nbsp;·&nbsp;
    <a href="../zh-CN/README.md">🇨🇳 阅读中文版</a>
    &nbsp;·&nbsp;
    <a href="../es/README.md">🇪🇸 Lee esto en español</a>
  </p>
  <p align="center">
    <a href="../hi/README.md">🇮🇳 हिन्दी में पढ़ें</a>
    &nbsp;·&nbsp;
    🇸🇦 <b>اقرأ بالعربية</b>
    &nbsp;·&nbsp;
    <a href="../pt-BR/README.md">🇧🇷 Leia em português</a>
    &nbsp;·&nbsp;
    <a href="../fr/README.md">🇫🇷 Lire en français</a>
  </p>
  <p align="center">
    <a href="../de/README.md">🇩🇪 Auf Deutsch lesen</a>
    &nbsp;·&nbsp;
    <a href="../ja/README.md">🇯🇵 日本語で読む</a>
    &nbsp;·&nbsp;
    <a href="../ko/README.md">🇰🇷 한국어로 읽기</a>
    &nbsp;·&nbsp;
    <a href="../sv/README.md">🇸🇪 Läs på svenska</a>
  </p>
<!-- i18n-bar:end -->

<p align="center" dir="rtl"><sub>🌐 ترجمة لملف <a href="../../../README.md">README الروسي</a>. الوثائق التفصيلية مترجمة أيضًا، والروابط أدناه تقود إلى الصفحات المترجمة. إذا اختلفت الترجمة عن الأصل فالعبرة بالأصل. لا تزال رسائل وحدة التحكم (الكونسول) ولقطات الشاشة والرسوم البيانية تحمل نصوصًا بالروسية. أُنجزت الترجمة بالذكاء الاصطناعي ولم يراجعها ناطقون أصليون. إذا وجدت أخطاءً فراسل <a href="https://github.com/damir-lebedev">Damir Lebedev</a> أو أبلغ عنها في <a href="https://github.com/damir-lebedev/OpenPlaneProject/issues">متتبّع المشكلات</a>.</sub></p>

<div dir="rtl">

<p align="center" dir="ltr">
  OpenPlane — طيار آلي مفتوح للطائرات
</p>

<p align="center" dir="ltr">
  
  
  
  <br>
  
  
  
  
</p>

<h3 align="center">أطفئ جهاز التحكم عن بُعد، فتعود الطائرة إلى المنزل وحدها وتدور فوق رأسك.</h3>
<p align="center">هذا ليس رسومًا متحركة: <b>البرنامج الثابت كله</b> يقود نموذج طائرة في حلقة مغلقة — بايتات iBUS نفسها عند الدخل، وإشارة PWM نفسها عند الخرج.</p>

<p align="center" dir="ltr">
  فقدان الاتصال: الطائرة تعود إلى المنزل وحدها وتدور
</p>

---

## ⚡ في 30 ثانية

| | |
|---|---|
| **ما هذا** | وحدة تحكم في الطيران وطيار آلي مفتوحان للطائرات اللاسلكية. اللوحة الرئيسية هي STM32H743 (لوحة من فئة Pixhawk): على لوحة DevEBox **يعمل البرنامج الثابت فعلًا ويُقاد بجهاز التحكم عن بُعد** — [يوجد فيديو](#-stm32h743-تدبّ-فيها-الحياة-على-اللوحة)، والحساسات تُوصَل الآن. أما الأساس السابق فهو ESP32-S3 بنحو 10 دولارات، وقد اجتاز منصة الاختبار بكل الحساسات. |
| **ماذا يستطيع** | 12 وضع طيران — من التثبيت إلى العودة إلى المنزل، والدوران حول نقطة GPS، والإطلاق باليد، والهبوط الآلي، و**التحليق الشراعي في التيارات الحرارية**. أنبوب بيتو مصنوع من مقياسَي ضغط رخيصين. قياس عن بُعد عبر MAVLink إلى QGroundControl وMission Planner. |
| **الميزة الأساسية** | أي مفتاح أو مقبض في جهاز التحكم = أي وظيفة. **سطر واحد** في `Controls.h` — ولا يعود SwD وضع RTH بل إسقاطًا للحمولة. |
| **لماذا يمكن الوثوق به** | 387 اختبارًا آليًا (إضافة إلى 9 على اللوحة نفسها ببطاقة SD حقيقية)، و98% من الشيفرة مغطاة بالاختبارات، و24 عملية بناء «لوحة × حساسات» دون تحذير واحد، ومحاكاة بحلقة مغلقة لكل وضع. |
| **بصراحة** | حتى الآن طار الوضع اليدوي فقط (النموذج الأولي الأول). واختُبرت STM32H743 حتى الآن على منصة الاختبار فقط ودون حساسات. أما الطيار الآلي فقد جرى التحقق منه على المنصة وبالاختبارات والمحاكاة، وهو بانتظار اختبارات الطيران — [الوضع الحالي أدناه](#-الوضع-الحقيقي). |

---

## 🎛️ مفتاح = وظيفة. سطر واحد.

<div dir="ltr">

```cpp
// include/config/Controls.h
constexpr Binding BINDINGS[] = {
    Bind::modes  (Channels::SWC, MODE_MANUAL, MODE_STABILIZE, MODE_AUTO_TAKEOFF),
    Bind::feature(Channels::SWB, Feature::FLAPS),
    Bind::mode   (Channels::SWD, MODE_RTH),              // إلى المنزل ما دام المفتاح مفعّلًا
    Bind::knob   (Channels::VRA, Knob::STAB_GAIN),       // «أنعم / أكثر صلابة» أثناء الطيران مباشرة
    Bind::knob   (Channels::VRB, Knob::CRUISE_SPEED),
};
```

</div>

تريد التحليق الشراعي في التيارات الحرارية على SwD بدل RTH؟ اكتب `Bind::mode(Channels::SWD, MODE_SOARING)`. وإسقاط الحمولة على SwB؟ `Bind::feature(Channels::SWB, Feature::PAYLOAD_DROP)`. وإن أخطأت، كأن تضع وضعين على مفتاح واحد أو تشغل إحدى العصيّ، **فلن ينجح البناء**: المترجم هو الذي يفحص الجدول (`static_assert`). وعند التشغيل تطبع الطائرة بنفسها ما الذي يقوم به كل مفتاح.

**12 وضعًا · 10 وظائف · 7 مقابض** — كلها مع أمثلة في [مرجع الطيار الآلي](AUTOPILOT_GUIDE.md).

---

## ✈️ ما الذي يستطيعه الطيار الآلي

| | الوضع | الفكرة |
|---|---|---|
| 🕹️ | **MANUAL** | أسطح التحكم = العصيّ، كما لو لم يكن هناك جهاز تحكم في الطيران |
| 🧭 | **STABILIZE** | تحدد العصا الزاوية؛ وإذا تركتها اعتدلت الطائرة بنفسها |
| 📏 | **ALT_HOLD** | + يحافظ على الارتفاع بواسطة مقياس الضغط |
| 🌀 | **ACRO** | تحدد العصا معدل الدوران — للحركات البهلوانية |
| 🛣️ | **CRUISE** | يحافظ على الاتجاه والارتفاع والسرعة وحده؛ والعصيّ تصحح فقط |
| ⭕ | **LOITER** | دوائر فوق نقطة GPS (يُضبط نصف القطر بمقبض) |
| 🏠 | **RTH** | إلى المنزل على ارتفاع 40 m ودوائر فوق الرأس؛ ويُفعَّل تلقائيًا عند فقدان الاتصال |
| 🛫 | **AUTO_TAKEOFF** | إقلاع من المدرج بدفعة الخانق التي يعطيها الطيار |
| 🤾 | **LAUNCH** | إطلاق باليد: يدور المحرك بعد الرمي، ثم يبدأ الصعود |
| 🛬 | **AUTO_LAND** | انسياب ثم تسوية قرب الأرض |
| 🦅 | **SOARING** | المحرك مطفأ، ويجد التيارات الحرارية ويدور فيها |
| 🆘 | **RESCUE** | «النجدة»: الجناحان مستويان والأنف إلى الأعلى — للخروج من أي حلزون |

إضافة إلى ذلك: السياج الجغرافي، والضبط التلقائي (auto-trim) للطائرة «المائلة»، وتنسيق الانعطاف، والحماية من الانهيار الهوائي (stall) بواسطة أنبوب بيتو، والفلابات ومكبح الهواء، وإسقاط الحمولة، وكاميرا مثبَّتة، وصافرة «ابحث عني في العشب».

---

## 📈 كل وضع يطير — في حلقة مغلقة

ليس «دالة أعادت رقمًا»، بل **رحلة طيران**: جهاز التحكم عن بُعد، ثم إطار iBUS، ثم البرنامج الثابت، ثم PWM، ثم انحراف أسطح التحكم، ثم نموذج طائرة بقوة رفع وانهيار هوائي ورياح وتيارات حرارية، ثم الحساسات، ثم البرنامج الثابت من جديد. وتشكل 14 رحلة كهذه جزءًا من الاختبارات المعتادة (`pio test -e native`).

<p align="center" dir="ltr">RTH وLOITER والسياج الجغرافي وفقدان الاتصال — منظر من الأعلى</p>

<table>
  <tr>
    <td width="50%">التحليق الشراعي: كسب الارتفاع في تيار حراري دون محرك</td>
    <td width="50%">الخروج من الميلان ومن الحلزون</td>
  </tr>
  <tr>
    <td>🦅 عثرت على تيار حراري بنفسها وكسبت ارتفاعًا <b>والمحرك مطفأ</b> — فمقياس معدل الصعود بالطاقة الكلية لا يخلط بين «سحب العصا» وبين تيار صاعد.</td>
    <td>🆘 ميل بزاوية 60° — وبعد ثوانٍ يعود الأفق مستويًا. يخرج RESCUE الطائرة من حلزون بميل 70° وأنف منخفض بزاوية −40°.</td>
  </tr>
  <tr>
    <td>الإطلاق باليد والهبوط الآلي</td>
    <td>أنبوب بيتو من مقياسَي ضغط</td>
  </tr>
  <tr>
    <td>🤾 رمي باليد، ولا يدور المحرك إلا بعد ابتعاد اليد عن المروحة، ثم صعود. 🛬 الهبوط: انسياب وتسوية على ارتفاع 3 m.</td>
    <td>🌬️ السرعة الجوية من أنبوب مصنوع من مقياسَي ضغط <b>كثيري الضجيج</b> مع انزياح 150 Pa بين الشريحتين — الخطأ أقل من 0.5 m/s.</td>
  </tr>
</table>

---

## 🌬️ أنبوب بيتو بأقل التكاليف

جهاز قياس السرعة الجوية الجيد يكلف نصف وحدة التحكم في الطيران تقريبًا. وهنا **مقياسا ضغط**: BMP581 في الأنبوب (الضغط الكلي) والمقياس الرئيسي في جسم الطائرة (الضغط الساكن). يصفّر البرنامج الثابت الفرق بين الشريحتين على الأرض، ويرشّح القراءات، ويحسب كثافة الهواء من الارتفاع ودرجة الحرارة، ويلاحظ إن بُدِّلت الخراطيم. والنتيجة: يحافظ CRUISE على **السرعة الجوية** لا على الخانق؛ وحماية من الانهيار الهوائي؛ وسرعة صادقة في القياس عن بُعد. طريقة التجميع في [المرجع](AUTOPILOT_GUIDE.md#أنبوب-بيتو-من-صنع-يديك).

---

## 📡 محطة التحكم الأرضية: المتصفح أو QGroundControl

<table>
  <tr>
    <td width="46%">لوحة المعلومات عبر الويب: الحساسات والطيار الآلي والملاحة</td>
    <td>
      <b>ESP32 — لوحة معلومات ويب من الطائرة مباشرة.</b> نقطة الوصول <code>OpenPlane-Debug</code> والعنوان <code>192.168.4.1</code>: قنوات جهاز التحكم عن بُعد، والمخارج، وجميع الحساسات، والوضع، والملاحة، وتغيير الوضع وضبط PID أثناء الطيران. بلا تطبيقات ولا أجهزة إضافية.<br><br>
      <b>STM32H743 — MAVLink عبر مودم راديو.</b> يرى QGroundControl وMission Planner الطائرة على أنها طائرة ArduPilot: الأفق، وخريطة عليها نقطة المنزل، والسرعة من أنبوب بيتو، والأوضاع بأسماء ArduPlane، وPID من نافذة المعاملات، وتغيير الوضع بزر. لا يمكن التسليح (ARM) من الأرض، بل بمفتاح فقط: فهذا أأمن.<br><br>
      أُطر MAVLink مطابَقة بايتًا ببايت مع المرجع <code>pymavlink</code>.
    </td>
  </tr>
</table>

---

## 📼 الصندوق الأسود

تسجّل اللوحة كل رحلة: IMU بتردد 500 Hz، والزوايا وقرارات الطيار الآلي، وPID، وكل المخارج، والعصيّ، ومقياس الضغط، والبوصلة، وGPS، والبطارية، والأحداث — من التسليح (ARM) ورفع الخانق حتى الهبوط، مع 10 ثوانٍ قبل البداية. يسجّل **ESP32-S3** في الفلاش المدمج (13.9 MB، نحو 11 دقيقة)، ويسجّل **STM32H743** على بطاقة SD (64 MB، نحو ساعة؛ وتبقى البطاقة FAT32 عادية، ويكتب البرنامج الثابت في ملف أُنشئ مسبقًا اسمه `BLACKBOX.BIN`). ولا يجري المسح إلا على الأرض. وبعد الرحلة ينزّل الأمر `python tools/blackbox.py download` الرحلة عبر USB ويقسمها إلى ملفات CSV؛ ويمكن أيضًا فك رحلات بطاقة SD دون اللوحة: `python tools/blackbox.py ring E:/BLACKBOX.BIN`. التفاصيل في [BLACKBOX.md](BLACKBOX.md).

---

## 🔩 العتاد: برنامج ثابت واحد — أربع لوحات واثنا عشر حساسًا

| اللوحة | الحالة | ما الذي جرى التحقق منه |
|---|---|---|
| **STM32H743VIT6** | ✅ الرئيسية · 🔧 DevEBox، الحساسات قيد التوصيل + 🧪 اختبارات | على اللوحة: الإقلاع ووحدة التحكم النصية عبر USB و**بطاقة SD والصندوق الأسود** (اختبارات على اللوحة) و**استقبال iBUS والتسليح (ARM) والتحكم في السيرفو والمحرك بجهاز التحكم عن بُعد** (الإطلاق موثَّق بالفيديو)؛ وعلى الحاسوب: البرنامج الثابت كله — مهام FreeRTOS والفلاش وMAVLink وI2C وSPI. ولم تُوصَّل حساسات باللوحة بعد |
| **ESP32-S3 N16R8** | ✅ الرئيسية السابقة، على المنصة | جميع الحساسات والسيرفو وiBUS وOLED ولوحة المعلومات مباشرة؛ والبرنامج الثابت كله في الاختبارات |
| **ESP32 38-pin** | 🧪 اختبارات | البرنامج الثابت كله في الاختبارات مع طقم ICM-45686 |
| **ESP32-C3 SuperMini** | ✈️ طارت (يدويًا) | النموذج الأولي الأول؛ وبناء جميع الأطقم |

| الحساس | ما هو | الناقل |
|---|---|---|
| **LSM6DSV** + **QMC6309** | IMU + بوصلة (وحدة) | I2C / SPI |
| **ICM-45686** + **QMC6309** | IMU + بوصلة (بديل) | I2C / SPI |
| **SPL06-001** | مقياس ضغط جسم الطائرة | I2C / SPI |
| **BMP581** | مقياس الضغط الرئيسي ومقياس الضغط في أنبوب بيتو | I2C / SPI |
| MPU6050/6500, ICM-42688, BMP388, BME280, QMC5883P/L | حساسات المنصة والقديمة | I2C / SPI |
| **u-blox M10** | GPS، 10 Hz، UBX | UART |

يُغيَّر الحساس بسطر واحد (`SENSOR_KIT_LSM6DSV_PITOT`)، وتُغيَّر اللوحة بعلَم بناء واحد. وتُبنى كل اللوحات الأربع × 6 أطقم حساسات دون تحذيرات: [`tools/build_matrix.sh`](../../../tools/build_matrix.sh).

<table>
  <tr>
    <td width="50%">المنصة: ESP32-S3 مع جميع الحساسات</td>
    <td width="50%">اختبار قوة دفع المحرك</td>
  </tr>
  <tr>
    <td>منصة ESP32-S3: IMU ومقياس الضغط والبوصلة وOLED والسيرفو والمستقبل.</td>
    <td>اختبار مجموعة المحرك والمروحة.</td>
  </tr>
</table>

### ‏🎥 STM32H743 تدبّ فيها الحياة على اللوحة

يعمل البرنامج الثابت الخاص بـ STM32H743 على لوحة DevEBox **دون أي حساس** ويُقاد بجهاز تحكم عادي: مستقبل iBUS والتسليح (ARM) والسيرفو والمحرك تستجيب للعصيّ والمفاتيح في الوضع اليدوي. وقد صُوّر الإطلاق كله بالفيديو.

▶️ **[شاهد الإطلاق بالفيديو](https://t.me/lisnmylife/420)**

ما الذي يثبته هذا: أن السلسلة «جهاز التحكم عن بُعد، ثم iBUS، ثم البرنامج الثابت، ثم PWM» تعمل على عتاد حقيقي لا في الاختبارات فقط. وما لم يثبت بعد: لم تُوصَّل بهذه اللوحة أي حساسات (IMU أو مقياس ضغط أو GPS)، ولذلك لم تُجرَّب عليها أوضاع الطيار الآلي حتى الآن.

---

## 🧪 جودة يمكن التحقق منها

| | |
|---|---|
| **387 اختبارًا آليًا** | الوحدات، وبرامج تشغيل الشرائح المفحوصة على مستوى السجلات، ورحلات بحلقة مغلقة، والبرنامج الثابت لـ ESP32 وSTM32 **بالكامل** على الحاسوب؛ إضافة إلى 9 اختبارات على لوحة STM32 نفسها ببطاقة SD حقيقية |
| **98.3% من الأسطر، 87.7% من الفروع** | تغطية `gcovr`، بما فيها شيفرة STM32 |
| **24/24 عملية بناء** | 4 لوحات × 6 أطقم حساسات، `-Wall -Wextra`، دون أي تحذير |
| **0 ملاحظات** | cppcheck وclang-tidy على الشيفرة كلها |
| **مراجع لا نسخ شيفرة** | معادلات الحساسات وفق أوراق البيانات (Bosch وST وTDK وGoertek)، وMAVLink وفق pymavlink |

<div dir="ltr">

```bash
pio test -e native -e native-stm32   # جميع الاختبارات، نحو 1.5 دقيقة، دون حاجة إلى عتاد
```

</div>

التفاصيل في [TESTING.md](TESTING.md).

---

## 🧠 كيف هو مبنيّ

<div dir="ltr">

```mermaid
flowchart LR
    RC["جهاز التحكم FS-i6<br/>iBUS"] --> SW["PilotSwitches<br/>Controls.h"]
    SENS["IMU · مقاييس الضغط · البوصلة<br/>GPS · أنبوب بيتو"] --> AP
    SW --> AP["Autopilot<br/>12 وضعًا · الملاحة<br/>failsafe · السياج الجغرافي"]
    AP --> FC["FlightController<br/>ARM · المازج · الفلابات"]
    FC --> OUT["سيرفو · ESC<br/>الحمولة · الكاميرا"]
    AP -.-> TLM["لوحة Wi-Fi<br/>MAVLink · OLED"]
```

</div>

- **‏C++ على ملفات الترويسة فقط (header-only)**، ووحدة ترجمة واحدة، ودون ذاكرة ديناميكية في حلقة الطيران. تفضّل `.h/.cpp`؟ لك فرع موازٍ هو [`feature/split-headers`](https://github.com/damir-lebedev/OpenPlaneProject/tree/feature/split-headers): يُولَّد من هذا الفرع بسكربت، ويأتي البرنامج الثابت مع LTO بالحجم نفسه.
- **‏HAL** — الطبقة الوحيدة التي تعرف المتحكم الدقيق: اللوحة الجديدة تعني `Board` جديدًا، لا طيارًا آليًا أُعيدت كتابته.
- **برنامج تشغيل الحساس لا يعرف الناقل**: فالفئة نفسها تعمل عبر I2C وSPI.
- **الأمان بترتيب العمليات**: فقدان الاتصال > ARM > الوضع > الخانق؛ ولا يستطيع أي وضع تمرير الخانق متجاوزًا ARM.

التفاصيل في [ARCHITECTURE.md](ARCHITECTURE.md).

---

## 🚀 بداية سريعة

<div dir="ltr">

```bash
pip install platformio
git clone https://github.com/damir-lebedev/OpenPlaneProject && cd OpenPlaneProject
pio run -e stm32h743-devebox -t upload                    # DevEBox H743: USB DFU، ووحدة التحكم النصية عبر USB
pio run -e esp32-s3 -t upload && pio device monitor     # ESP32-S3
pio run -e stm32h743 -t upload                            # STM32H743 (ST-Link)
```

</div>

‏DevEBox: لا يوجد في اللوحة زر BOOT0 — قبل أول رفع صِل الطرف BT0 بـ 3V3 واضغط RST؛ وبعد ذلك يعيد الزر `D` في وحدة التحكم النصية تشغيل اللوحة إلى المحمّل بنفسه ([التفاصيل](DEVELOPER_GUIDE.md#stm32h743)).

في مراقب المنفذ التسلسلي: `h` — القائمة، `b` — أي الشرائح ظاهرة على النواقل، `s` — الحساسات، `p` — فحص المخارج (انزع المروحة!). ثم — [دليل الطيار](PILOT_GUIDE.md).

---

## 🟢 الوضع الحقيقي

| ماذا | أين جرى التحقق |
|---|---|
| التحكم اليدوي، المازج | ✈️ في الطيران (النموذج الأولي الأول، C3) |
| ARM وfailsafe والفلابات والسيرفو والمحرك | 🔧 على المنصة (S3) |
| STABILIZE | 🔧 على المنصة: تستجيب أسطح التحكم للميلان في الاتجاه الصحيح |
| حساسات المنصة (MPU6500 وBMP388 وQMC5883P) وOLED ولوحة المعلومات | 🔧 على المنصة |
| بقية الأوضاع والملاحة وأنبوب بيتو وMAVLink | 🧪 اختبارات ومحاكاة بحلقة مغلقة |
| الحساسات الجديدة (LSM6DSV وICM-45686 وQMC6309 وSPL06 وBMP581) | 🧪 محاكيات سجلات وفق أوراق البيانات |
| STM32H743: بطاقة SD والصندوق الأسود ووحدة التحكم النصية عبر USB | 🔧 على لوحة DevEBox (اختبارات على اللوحة) |
| STM32H743: iBUS وARM وPWM للسيرفو والمحرك والتحكم اليدوي | 🔧 على لوحة دون حساسات، موثَّق بالفيديو |
| STM32H743: الحساسات (IMU ومقياس الضغط والبوصلة وGPS) وأوضاع الطيار الآلي | 🧪 البرنامج الثابت كله على الحاسوب؛ ولم تُوصَّل حساسات باللوحة بعد |

نموذج الطائرة في المحاكاة مبسَّط، والمعاملات قيم ابتدائية. وكل وضع جديد يُجرَّب أولًا على ارتفاع، وإصبعك على مفتاح MANUAL.

---

## 🗺️ خارطة الطريق

- [x] ‏التحكم اليدوي وARM وfailsafe وبرنامج ثابت كائني التوجه ولوحة معلومات ويب
- [x] ‏منصة ESP32-S3 مع جميع الحساسات — مباشرة
- [x] ‏12 وضعًا، وملاحة GPS، وRTH عند فقدان الاتصال، وسياج جغرافي
- [x] ‏المفاتيح والمقابض بسطر واحد، وإسقاط الحمولة، والكاميرا، والضبط التلقائي
- [x] ‏أنبوب بيتو من مقياسَي ضغط، وحماية من الانهيار الهوائي
- [x] ‏حساسات جديدة: LSM6DSV وICM-45686 وQMC6309 وSPL06 وBMP581
- [x] ‏STM32H743: برنامج ثابت كامل وMAVLink وإعدادات في الفلاش
- [x] ‏محاكاة بحلقة مغلقة لجميع الأوضاع، والبرنامج الثابت كله في الاختبارات
- [x] ‏الصندوق الأسود: الرحلة في الفلاش (ESP32-S3) وعلى بطاقة SD (STM32H743)، والتنزيل والفك إلى CSV
- [x] ‏STM32H743 تعمل على اللوحة: جهاز التحكم عن بُعد، ثم iBUS، ثم السيرفو والمحرك (دون حساسات، بالفيديو)
- [ ] ‏STM32H743: توصيل الحساسات واجتياز منصة الاختبار كما جرى مع ESP32-S3
- [ ] اختبارات طيران للطيار الآلي على هيكل الطائرة الجديد
- [ ] لوحة وحدة تحكم في الطيران خاصة ([FC_BOARD.md](FC_BOARD.md)) على STM32H743
- [ ] الطيران عبر نقاط الطريق ومهام MAVLink
- [ ] تغذية راجعة تكيفية (المسودة الأولى جرى التحقق منها في المحاكاة)
- [ ] مستشعر للتيار والبطارية، وقياس عن بُعد إلى جهاز التحكم (iBUS-SENS)
- [ ] توصيل ذاتي: المسار، ثم إسقاط الحمولة، ثم العودة إلى المنزل

التفاصيل في [ROADMAP.md](ROADMAP.md).

---

## 💼 للشركاء والمستثمرين

الطائرات الصغيرة للتوصيل ومراقبة المناطق إما منصات مغلقة باهظة وإما مشاريع هواة متفرقة. تستهدف OpenPlane المنطقة الوسطى: **طيارًا آليًا مفتوحًا قابلًا للتحقق على عتاد واسع الانتشار**، تغطي الاختبارات كل وظيفة فيه ويمكن تكييفه مع المهمة — توصيل الأدوية إلى الأماكن التي يصعب الوصول إليها، ومراقبة الحقول والغابات، وأعمال البحث.

ما أُنجز حتى الآن بإمكانياتنا الذاتية: معمارية تنتقل بين اللوحات دون إعادة كتابة؛ وطيار آلي بمجموعة كاملة من الأوضاع؛ وبنية اختبارات تظهر عليها الميزات الجديدة بسرعة دون أن تكسر القديمة. وما ستسرّعه الموارد: اختبارات الطيران، ولوحة وحدة تحكم في الطيران خاصة على STM32H743، والطيران عبر نقاط الطريق وإسقاط الحمولة. إلى أين ولماذا — في [ROADMAP.md](ROADMAP.md).

---

## 📚 الوثائق

| الوثيقة | لمن |
|---|---|
| [AUTOPILOT_GUIDE.md](AUTOPILOT_GUIDE.md) | للطيار: كل وضع ووظيفة ومقبض، وكيف تُربط بمفتاح، وأنبوب بيتو، والمحطة الأرضية |
| [PILOT_GUIDE.md](PILOT_GUIDE.md) | التجميع، وتوزيع الأطراف، وجهاز التحكم، وfailsafe، والرحلة الأولى |
| [DEVELOPER_GUIDE.md](DEVELOPER_GUIDE.md) | للمطوّر: الملفات، واصطلاحات الإشارات، وواجهة API، وكيف تضيف حساسًا أو وضعًا أو لوحة |
| [ARCHITECTURE.md](ARCHITECTURE.md) | الطبقات والمهام ودورة التحكم وآلات الحالات |
| [TESTING.md](TESTING.md) | الاختبارات والمحاكاة والتغطية والتحليل |
| [reference/](reference/README.md) | مرجع لكل فئة |
| [FC_BOARD.md](FC_BOARD.md) · [ROADMAP.md](ROADMAP.md) | لوحة وحدة التحكم في الطيران · إلى أين يتجه المشروع |
| [airframe/](airframe/README.md) | هيكل Astro-Cargo: مشروع Fusion 360 وملفات STL للطباعة، والعيوب المعروفة في الإصدار v2 |

> **مشروع ذو صلة:** [esp32-rc-joystick](https://github.com/damir-lebedev/esp32-rc-joystick) — جهاز التحكم FS-i6 كذراع تحكم USB للمحاكي على ESP32-S3 نفسها: تدرّب ساعات في المحاكي أولًا، ثم في الحقل.

---

## 🤝 المشاركة

نحتاج إلى أيدٍ وعقول: الديناميكا الهوائية وهواية صنع النماذج الطائرة، والطباعة ثلاثية الأبعاد ومتانة المواد، ولغة C++ للأنظمة المدمجة، والحساسات والطيارات الآلية، وواجهات المحطة الأرضية. أرسلوا القضايا (Issues) وطلبات الدمج (pull requests) إلى الفرع `main`؛ وابدؤوا بـ [DEVELOPER_GUIDE.md](DEVELOPER_GUIDE.md).

## 📜 الرخصة

‏[OpenPlane License](LICENSE.md) رخصة مبنية على MIT مع شروط إضافية. يجوز استخدام الشيفرة والوثائق وملفات النموذج ونسخها وتعديلها وبيعها، بما في ذلك في المنتجات التجارية. والشروط هي:

1. **اذكر المؤلف — Damir Lebedev (Damn / Проклятый).** يجب أن يظهر الاسم في مكان يراه مستخدمو منتجك: في الوثائق أو README أو صفحة «حول». واترك نص الرخصة مع الشيفرة.
2. **الاستخدام العسكري محظور.** لا يجوز استخدام المشروع لصالح الجيوش والتنظيمات شبه العسكرية، ولا في الحرب، ولا لصنع الأسلحة والذخائر وأنظمة إيصالها وتصويبها.
3. **لا تُلحق الضرر بالأشخاص أو الممتلكات عمدًا دون موافقتهم الكتابية المسبقة على هذا الضرر.** يجوز لك إتلاف معداتك أنت إن لم يكن في ذلك خطر على أحد: مثل إطلاق النار من مسدس هوائي على طائرتك المسيّرة الخاصة. أما إيذاء الناس أو قتلهم فلا يجوز.
4. **التزم بقواعد السلامة والقانون** عند التجميع والاختبار والطيران.

إذا خُرقت الشروط انتهى الإذن باستخدام المشروع. وبسبب حظر بعض أنواع الاستخدام فهذه ليست رخصة «مفتوحة» بمفهوم OSI: الشيفرة متاحة للقراءة والنسخ والتعديل، لكن المشروع رسميًا من النوع source-available لا open source.

النص الإنجليزي في ملف [LICENSE](LICENSE.md) هو وحده ذو القوة القانونية: أما ترجمات الرخصة إلى اللغات الأخرى فمقدَّمة للتسهيل.

يتحكم البرنامج الثابت في طائرة وهو غير معتمد. وكل ما تفعله به فعلى مسؤوليتك؛ ولا يتحمل المؤلف أي مسؤولية.

<div dir="ltr">

```text
OpenPlane © 2026 Damir Lebedev (Damn / Проклятый) — https://github.com/damir-lebedev/OpenPlaneProject
```

</div>

<p align="center"><i>تعطّل النموذج الأولي الأول في أول رحلة له — ولهذا فكل شيء هنا مكشوف: الشيفرة والاختبارات والمشكلات. ابنوه، واكسروه، وأصلحوه معنا.</i></p>

</div>

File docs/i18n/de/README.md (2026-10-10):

<!-- i18n-bar:start -->
  <p align="center">
    <a href="../../../README.md">🇷🇺 Читать на русском</a>
    &nbsp;·&nbsp;
    <a href="../en/README.md">🇬🇧 Read this in English</a>
    &nbsp;·&nbsp;
    <a href="../zh-CN/README.md">🇨🇳 阅读中文版</a>
    &nbsp;·&nbsp;
    <a href="../es/README.md">🇪🇸 Lee esto en español</a>
  </p>
  <p align="center">
    <a href="../hi/README.md">🇮🇳 हिन्दी में पढ़ें</a>
    &nbsp;·&nbsp;
    <a href="../ar/README.md">🇸🇦 اقرأ بالعربية</a>
    &nbsp;·&nbsp;
    <a href="../pt-BR/README.md">🇧🇷 Leia em português</a>
    &nbsp;·&nbsp;
    <a href="../fr/README.md">🇫🇷 Lire en français</a>
  </p>
  <p align="center">
    🇩🇪 <b>Auf Deutsch lesen</b>
    &nbsp;·&nbsp;
    <a href="../ja/README.md">🇯🇵 日本語で読む</a>
    &nbsp;·&nbsp;
    <a href="../ko/README.md">🇰🇷 한국어로 읽기</a>
    &nbsp;·&nbsp;
    <a href="../sv/README.md">🇸🇪 Läs på svenska</a>
  </p>
<!-- i18n-bar:end -->

<p align="center"><sub>🌐 Übersetzung der <a href="../../../README.md">russischen README</a>. Die ausführliche Dokumentation ist ebenfalls übersetzt, und die Links unten führen zu den übersetzten Seiten. Weichen Übersetzung und Original voneinander ab, gilt das Original. Konsolenmeldungen, Screenshots und Diagramme enthalten noch russische Beschriftungen. Die Übersetzung wurde von einer KI erstellt und nicht von Muttersprachlern geprüft. Fehler bitte an <a href="https://github.com/damir-lebedev">Damir Lebedev</a> melden oder im <a href="https://github.com/damir-lebedev/OpenPlaneProject/issues">Issue-Tracker</a> eintragen.</sub></p>

<p align="center">
  OpenPlane – ein offener Autopilot für Flugzeuge
</p>

<p align="center">
  
  
  
  <br>
  
  
  
  
</p>

<h3 align="center">Sender aus – und das Flugzeug fliegt von selbst nach Hause und kreist über Ihnen.</h3>
<p align="center">Das ist kein Zeichentrickfilm: <b>die gesamte Firmware</b> fliegt ein Flugzeugmodell im geschlossenen Regelkreis – dieselben iBUS-Bytes am Eingang, dasselbe PWM am Ausgang.</p>

<p align="center">
  Verbindungsverlust: Das Flugzeug kehrt von selbst nach Hause zurück und kreist
</p>

---

## ⚡ In 30 Sekunden

| | |
|---|---|
| **Was es ist** | Eine offene Flugsteuerung und ein Autopilot für ferngesteuerte Flugzeuge. Das Hauptboard ist der STM32H743 (ein Board der Pixhawk-Klasse): Auf einem DevEBox-Board **läuft die Firmware bereits und lässt sich per Sender steuern** – [es gibt ein Video](#-der-stm32h743-erwacht-auf-dem-board-zum-leben), gerade werden die Sensoren angeschlossen. Die frühere Basis ist ein ESP32-S3 für rund 10 $, der den Prüfstand mit allen Sensoren durchlaufen hat. |
| **Was er kann** | 12 Flugmodi – von der Stabilisierung bis zur Rückkehr nach Hause, Kreisen per GPS, Handstart, Autolandung und **Thermikfliegen**. Ein Pitotrohr aus zwei billigen Barometern. MAVLink-Telemetrie für QGroundControl und Mission Planner. |
| **Der Clou** | Jeder Schalter oder Drehregler am Sender = jede beliebige Funktion. **Eine Zeile** in `Controls.h` – und SwD ist nicht mehr RTH, sondern ein Lastabwurf. |
| **Warum man dem trauen kann** | 387 automatische Tests (dazu 9 auf dem Board selbst mit einer echten SD-Karte), 98 % des Codes durch Tests abgedeckt, 24 Builds „Board × Sensoren“ ohne eine einzige Warnung, Simulationen jedes Modus im geschlossenen Regelkreis. |
| **Ehrlich gesagt** | Bisher ist nur der manuelle Modus geflogen (der erste Prototyp). Der STM32H743 wurde bisher nur auf dem Prüfstand und ohne Sensoren getestet. Der Autopilot wurde auf dem Prüfstand, durch Tests und in Simulationen überprüft und wartet auf die Flugerprobung – [Stand weiter unten](#-ehrlicher-stand). |

---

## 🎛️ Ein Schalter = eine Funktion. Eine Zeile.

```cpp
// include/config/Controls.h
constexpr Binding BINDINGS[] = {
    Bind::modes  (Channels::SWC, MODE_MANUAL, MODE_STABILIZE, MODE_AUTO_TAKEOFF),
    Bind::feature(Channels::SWB, Feature::FLAPS),
    Bind::mode   (Channels::SWD, MODE_RTH),              // nach Hause, solange eingeschaltet
    Bind::knob   (Channels::VRA, Knob::STAB_GAIN),       // „weicher / härter“ direkt im Flug
    Bind::knob   (Channels::VRB, Knob::CRUISE_SPEED),
};
```

Sie möchten auf SwD statt RTH das Thermikfliegen haben? `Bind::mode(Channels::SWD, MODE_SOARING)`. Einen Lastabwurf auf SwB? `Bind::feature(Channels::SWB, Feature::PAYLOAD_DROP)`. Unterläuft Ihnen ein Fehler – etwa zwei Modi auf einem Schalter oder ein bereits belegter Knüppel –, **schlägt der Build fehl**: Die Tabelle prüft der Compiler (`static_assert`). Beim Einschalten gibt das Flugzeug selbst aus, was auf welchem Schalter liegt.

**12 Modi · 10 Funktionen · 7 Drehregler** – alles mit Beispielen in der [Autopilot-Referenz](AUTOPILOT_GUIDE.md).

---

## ✈️ Was der Autopilot kann

| | Modus | Kurz gesagt |
|---|---|---|
| 🕹️ | **MANUAL** | Ruder = Knüppel, wie ohne Flugsteuerung |
| 🧭 | **STABILIZE** | der Knüppel gibt den Winkel vor; loslassen, und das Flugzeug richtet sich von selbst waagerecht aus |
| 📏 | **ALT_HOLD** | + hält die Höhe per Barometer |
| 🌀 | **ACRO** | der Knüppel gibt die Drehrate vor – für Kunstflug |
| 🛣️ | **CRUISE** | Kurs, Höhe und Geschwindigkeit halten sich selbst; die Knüppel korrigieren nur |
| ⭕ | **LOITER** | Kreise über einem GPS-Punkt (der Radius wird mit einem Drehregler eingestellt) |
| 🏠 | **RTH** | nach Hause auf 40 m und Kreise über Ihrem Kopf; schaltet sich bei Verbindungsverlust selbst ein |
| 🛫 | **AUTO_TAKEOFF** | Start von der Piste mit dem Gas des Piloten |
| 🤾 | **LAUNCH** | Handstart: Der Motor läuft nach dem Wurf an, dann folgt der Steigflug |
| 🛬 | **AUTO_LAND** | Gleitflug und Abfangen dicht über dem Boden |
| 🦅 | **SOARING** | Motor aus, findet Thermik und kreist darin |
| 🆘 | **RESCUE** | „Hilfe“: Flügel waagerecht, Nase hoch – aus jeder Spirale heraus |

Dazu: Geofence, Auto-Trimmung für ein „schiefes“ Flugzeug, Kurvenkoordination, Überziehschutz per Pitotrohr, Klappen und Luftbremse, Lastabwurf, stabilisierte Kamera und ein Summer „Such mich im Gras“.

---

## 📈 Jeder Modus fliegt – im geschlossenen Regelkreis

Nicht „eine Funktion hat eine Zahl zurückgegeben“, sondern ein **Flug**: Sender → iBUS-Frame → Firmware → PWM → Ruderausschläge → Flugzeugmodell mit Auftrieb, Strömungsabriss, Wind und Thermik → Sensoren → wieder die Firmware. 14 solcher Flüge gehören zu den gewöhnlichen Tests (`pio test -e native`).

<p align="center">RTH, LOITER, Geofence und Verbindungsverlust – Ansicht von oben</p>

<table>
  <tr>
    <td width="50%">Thermikfliegen: Höhengewinn in der Thermik ohne Motor</td>
    <td width="50%">Ausleiten aus Schräglage und aus einer Spirale</td>
  </tr>
  <tr>
    <td>🦅 Hat die Thermik selbst gefunden und Höhe gewonnen – <b>bei abgeschaltetem Motor</b>. Das Gesamtenergie-Variometer hält „Knüppel ziehen“ nicht für einen Aufwind.</td>
    <td>🆘 60° Schräglage – und nach wenigen Sekunden ist der Horizont wieder waagerecht. RESCUE holt das Flugzeug aus einer Spirale mit 70° Schräglage und −40° Nasenlage heraus.</td>
  </tr>
  <tr>
    <td>Handstart und Autolandung</td>
    <td>Pitotrohr aus zwei Barometern</td>
  </tr>
  <tr>
    <td>🤾 Handwurf → der Motor läuft erst an, wenn die Hand vom Propeller weg ist → Steigflug. 🛬 Landung: Gleitflug und Abfangen auf 3 m.</td>
    <td>🌬️ Fluggeschwindigkeit aus einem Rohr mit zwei <b>verrauschten</b> Barometern und 150 Pa Versatz zwischen den Chips – der Fehler liegt unter 0,5 m/s.</td>
  </tr>
</table>

---

## 🌬️ Ein Pitotrohr für ein paar Cent

Ein ordentlicher Fahrtmesser kostet so viel wie eine halbe Flugsteuerung. Hier sind es **zwei Barometer**: ein BMP581 im Rohr (Gesamtdruck) und das Hauptbarometer im Rumpf (statischer Druck). Die Firmware gleicht den Unterschied zwischen den Chips am Boden selbst auf null ab, filtert, berechnet die Luftdichte aus Höhe und Temperatur und bemerkt vertauschte Schläuche. Das bringt: CRUISE hält die **Luft**geschwindigkeit statt des Gases; Überziehschutz; eine ehrliche Geschwindigkeit in der Telemetrie. Der Aufbau steht in der [Referenz](AUTOPILOT_GUIDE.md#ein-pitotrohr-zum-selberbauen).

---

## 📡 Bodenstation: Browser oder QGroundControl

<table>
  <tr>
    <td width="46%">Web-Dashboard: Sensoren, Autopilot, Navigation</td>
    <td>
      <b>ESP32 – ein Web-Dashboard direkt vom Flugzeug.</b> Zugangspunkt <code>OpenPlane-Debug</code>, Adresse <code>192.168.4.1</code>: Senderkanäle, Ausgänge, alle Sensoren, Modus, Navigation, Moduswechsel und PID-Einstellung im laufenden Betrieb. Ohne Apps und ohne zusätzliche Hardware.<br><br>
      <b>STM32H743 – MAVLink über ein Funkmodem.</b> QGroundControl und Mission Planner sehen das Flugzeug als ArduPilot-Flugzeug: Horizont, Karte mit dem Startpunkt, Geschwindigkeit vom Pitotrohr, Modi unter ihren ArduPlane-Namen, PID aus dem Parameterfenster, Moduswechsel per Schaltfläche. ARM vom Boden aus ist nicht möglich, nur per Schalter: So ist es sicherer.<br><br>
      Die MAVLink-Frames wurden Byte für Byte mit der Referenz <code>pymavlink</code> abgeglichen.
    </td>
  </tr>
</table>

---

## 📼 Blackbox

Das Board zeichnet jeden Flug auf: IMU mit 500 Hz, Winkel und Entscheidungen des Autopiloten, PID, alle Ausgänge, Knüppel, Barometer, Kompass, GPS, Akku und Ereignisse – ab ARM und Gas bis zur Landung, mit 10 Sekunden Vorlauf. Der **ESP32-S3** schreibt in den eingebauten Flash (13,9 MB, etwa 11 Minuten), der **STM32H743** auf eine SD-Karte (64 MB, etwa eine Stunde; die Karte bleibt eine gewöhnliche FAT32-Karte, und die Firmware schreibt in eine vorab angelegte Datei `BLACKBOX.BIN`). Gelöscht wird nur am Boden. Nach dem Flug lädt `python tools/blackbox.py download` den Flug per USB herunter und zerlegt ihn in CSV-Dateien; Flüge von der SD-Karte lassen sich auch ohne das Board auswerten: `python tools/blackbox.py ring E:/BLACKBOX.BIN`. Details – in [BLACKBOX.md](BLACKBOX.md).

---

## 🔩 Hardware: eine Firmware – vier Boards, zwölf Sensoren

| Board | Status | Was geprüft wurde |
|---|---|---|
| **STM32H743VIT6** | ✅ Hauptboard · 🔧 DevEBox, Sensoren werden angeschlossen + 🧪 Tests | auf dem Board: Start, Konsole über USB, **SD-Karte und Blackbox** (Tests auf dem Board), **iBUS-Empfang, ARM und Steuerung von Servos und Motor per Sender** (der Start ist auf Video); auf dem PC: die ganze Firmware – FreeRTOS-Tasks, Flash, MAVLink, I2C und SPI. Sensoren wurden noch nicht an das Board angeschlossen |
| **ESP32-S3 N16R8** | ✅ früheres Hauptboard, auf dem Prüfstand | alle Sensoren, Servos, iBUS, OLED, Dashboard live; die ganze Firmware in den Tests |
| **ESP32 38-pin** | 🧪 Tests | die ganze Firmware in den Tests mit dem ICM-45686-Set |
| **ESP32-C3 SuperMini** | ✈️ ist geflogen (manuell) | der erste Prototyp; Build aller Sets |

| Sensor | Was es ist | Busse |
|---|---|---|
| **LSM6DSV** + **QMC6309** | IMU + Kompass (Modul) | I2C / SPI |
| **ICM-45686** + **QMC6309** | IMU + Kompass (Ersatz) | I2C / SPI |
| **SPL06-001** | Rumpfbarometer | I2C / SPI |
| **BMP581** | Hauptbarometer und Barometer im Pitotrohr | I2C / SPI |
| MPU6050/6500, ICM-42688, BMP388, BME280, QMC5883P/L | Prüfstands- und ältere Sensoren | I2C / SPI |
| **u-blox M10** | GPS, 10 Hz, UBX | UART |

Ein Sensor wird mit einer Zeile gewechselt (`SENSOR_KIT_LSM6DSV_PITOT`), ein Board mit einem Build-Flag. Alle 4 Boards × 6 Sensorsets bauen ohne Warnungen: [`tools/build_matrix.sh`](../../../tools/build_matrix.sh).

<table>
  <tr>
    <td width="50%">Prüfstand: ESP32-S3 mit allen Sensoren</td>
    <td width="50%">Schubtest des Motors</td>
  </tr>
  <tr>
    <td>Prüfstand mit dem ESP32-S3: IMU, Barometer, Kompass, OLED, Servos, Empfänger.</td>
    <td>Test der Antriebsgruppe aus Motor und Propeller.</td>
  </tr>
</table>

### 🎥 Der STM32H743 erwacht auf dem Board zum Leben

Die Firmware für den STM32H743 läuft auf einem DevEBox-Board **ohne einen einzigen Sensor** und lässt sich mit einem gewöhnlichen Sender steuern: iBUS-Empfänger, ARM, Servos und Motor reagieren im manuellen Modus auf Knüppel und Schalter. Der gesamte Start wurde auf Video festgehalten.

▶️ **[Den Start auf Video ansehen](https://t.me/lisnmylife/420)**

Was das beweist: Die Kette „Sender → iBUS → Firmware → PWM“ funktioniert auf echter Hardware und nicht nur in den Tests. Was noch nicht bewiesen ist: An dieses Board wurden keine Sensoren (IMU, Barometer, GPS) angeschlossen, daher wurden die Autopilot-Modi darauf noch nicht ausprobiert.

---

## 🧪 Nachprüfbare Qualität

| | |
|---|---|
| **387 automatische Tests** | Module, Treiber auf Ebene der Chipregister, Flüge im geschlossenen Regelkreis, die Firmware für ESP32 und STM32 **vollständig** auf dem PC; dazu 9 Tests auf dem STM32-Board selbst mit einer echten SD-Karte |
| **98,3 % der Zeilen, 87,7 % der Verzweigungen** | `gcovr`-Abdeckung, einschließlich des STM32-Codes |
| **24/24 Builds** | 4 Boards × 6 Sensorsets, `-Wall -Wextra`, null Warnungen |
| **0 Beanstandungen** | cppcheck und clang-tidy über den gesamten Code |
| **Referenzen statt Code-Kopien** | die Sensorformeln folgen den Datenblättern (Bosch, ST, TDK, Goertek), MAVLink folgt pymavlink |

```bash
pio test -e native -e native-stm32   # alle Tests, ~1,5 Minuten, keine Hardware nötig
```

Details – in [TESTING.md](TESTING.md).

---

## 🧠 Wie es aufgebaut ist

```mermaid
flowchart LR
    RC["Sender FS-i6<br/>iBUS"] --> SW["PilotSwitches<br/>Controls.h"]
    SENS["IMU · Barometer · Kompass<br/>GPS · Pitotrohr"] --> AP
    SW --> AP["Autopilot<br/>12 Modi · Navigation<br/>Failsafe · Geofence"]
    AP --> FC["FlightController<br/>ARM · Mixer · Klappen"]
    FC --> OUT["Servos · ESC<br/>Last · Kamera"]
    AP -.-> TLM["WLAN-Dashboard<br/>MAVLink · OLED"]
```

- **Header-only-C++**, eine einzige Übersetzungseinheit, kein dynamischer Speicher in der Flugschleife. Lieber `.h/.cpp`? Für Sie gibt es einen parallelen Branch, [`feature/split-headers`](https://github.com/damir-lebedev/OpenPlaneProject/tree/feature/split-headers): Er wird per Skript aus diesem erzeugt, und die Firmware mit LTO ist genauso groß.
- **HAL** – die einzige Schicht, die den Mikrocontroller kennt: Ein neues Board ist ein neues `Board`, kein umgeschriebener Autopilot.
- **Ein Sensortreiber kennt den Bus nicht**: Dieselbe Klasse arbeitet über I2C und über SPI.
- **Sicherheit durch die Reihenfolge der Operationen**: Verbindungsverlust > ARM > Modus > Gas; kein Modus kann das Gas an ARM vorbeischleusen.

Details – in [ARCHITECTURE.md](ARCHITECTURE.md).

---

## 🚀 Schnellstart

```bash
pip install platformio
git clone https://github.com/damir-lebedev/OpenPlaneProject && cd OpenPlaneProject
pio run -e stm32h743-devebox -t upload                    # DevEBox H743: USB-DFU, Konsole über USB
pio run -e esp32-s3 -t upload && pio device monitor     # ESP32-S3
pio run -e stm32h743 -t upload                            # STM32H743 (ST-Link)
```

DevEBox: Auf dem Board gibt es keine BOOT0-Taste – verbinden Sie vor dem ersten Flashen den Pin BT0 mit 3V3 und drücken Sie RST; danach startet die Taste `D` in der Konsole das Board selbstständig im Bootloader neu ([Details](DEVELOPER_GUIDE.md#stm32h743)).

Im seriellen Monitor: `h` – Menü, `b` – welche Chips auf den Bussen sichtbar sind, `s` – Sensoren, `p` – Ausgangstest (Propeller abnehmen!). Weiter – im [Pilotenleitfaden](PILOT_GUIDE.md).

---

## 🟢 Ehrlicher Stand

| Was | Wo geprüft |
|---|---|
| Manuelle Steuerung, Mixer | ✈️ im Flug (erster Prototyp, C3) |
| ARM, Failsafe, Klappen, Servos, Motor | 🔧 auf dem Prüfstand (S3) |
| STABILIZE | 🔧 auf dem Prüfstand: Die Ruder reagieren auf Neigungen in die richtige Richtung |
| Prüfstandssensoren (MPU6500, BMP388, QMC5883P), OLED, Dashboard | 🔧 auf dem Prüfstand |
| Übrige Modi, Navigation, Pitotrohr, MAVLink | 🧪 Tests und Simulationen im geschlossenen Regelkreis |
| Neue Sensoren (LSM6DSV, ICM-45686, QMC6309, SPL06, BMP581) | 🧪 Registeremulatoren nach den Datenblättern |
| STM32H743: SD-Karte, Blackbox, Konsole über USB | 🔧 auf dem DevEBox-Board (Tests auf dem Board) |
| STM32H743: iBUS, ARM, PWM für Servos und Motor, manuelle Steuerung | 🔧 auf dem Board ohne Sensoren, auf Video festgehalten |
| STM32H743: Sensoren (IMU, Barometer, Kompass, GPS) und Autopilot-Modi | 🧪 die ganze Firmware auf dem PC; Sensoren wurden noch nicht an das Board angeschlossen |

Das Flugzeugmodell in den Simulationen ist vereinfacht, die Koeffizienten sind Startwerte. Jeder neue Modus wird zuerst in der Höhe erprobt, den Finger auf dem MANUAL-Schalter.

---

## 🗺️ Fahrplan

- [x] Manuelle Steuerung, ARM, Failsafe, objektorientierte Firmware, Web-Dashboard
- [x] ESP32-S3-Prüfstand mit allen Sensoren – live
- [x] 12 Modi, GPS-Navigation, RTH bei Verbindungsverlust, Geofence
- [x] Schalter und Drehregler in einer Zeile, Lastabwurf, Kamera, Auto-Trimmung
- [x] Pitotrohr aus zwei Barometern, Überziehschutz
- [x] Neue Sensoren: LSM6DSV, ICM-45686, QMC6309, SPL06, BMP581
- [x] STM32H743: vollständige Firmware, MAVLink, Einstellungen im Flash
- [x] Simulationen aller Modi im geschlossenen Regelkreis, die ganze Firmware in den Tests
- [x] Blackbox: Flug im Flash (ESP32-S3) und auf einer SD-Karte (STM32H743), Download und Auswertung als CSV
- [x] STM32H743 läuft auf dem Board: Sender → iBUS → Servos und Motor (ohne Sensoren, auf Video)
- [ ] STM32H743: Sensoren anschließen und den Prüfstand so durchlaufen wie beim ESP32-S3
- [ ] Flugerprobung des Autopiloten an der neuen Flugzeugzelle
- [ ] Eine eigene Flugsteuerungsplatine ([FC_BOARD.md](FC_BOARD.md)) auf dem STM32H743
- [ ] Flug über Wegpunkte, MAVLink-Missionen
- [ ] Adaptive Rückführung (ein Entwurf ist bereits in der Simulation geprüft)
- [ ] Strom- und Akkusensor, Telemetrie zum Sender (iBUS-SENS)
- [ ] Autonome Zustellung: Route → Lastabwurf → nach Hause

Details – in [ROADMAP.md](ROADMAP.md).

---

## 💼 Für Partner und Investoren

Kleine Lieferflugzeuge und Überwachungsflugzeuge sind entweder geschlossene, teure Plattformen oder verstreute Hobbyprojekte. OpenPlane zielt auf die Mitte: **ein offener, überprüfbarer Autopilot auf Massenhardware**, bei dem jede Funktion durch Tests abgedeckt ist und an eine Aufgabe angepasst werden kann – Medikamentenlieferung an schwer erreichbare Orte, Überwachung von Feldern und Wäldern, Suchaktionen.

Was bereits aus eigener Kraft geschafft wurde: eine Architektur, die sich ohne Umschreiben zwischen Boards übertragen lässt; ein Autopilot mit vollständigem Modussatz; eine Testinfrastruktur, auf der neue Funktionen schnell entstehen und die alten nicht kaputtmachen. Was zusätzliche Mittel beschleunigen würden: die Flugerprobung, eine eigene Flugsteuerungsplatine auf dem STM32H743, der Flug über Wegpunkte und der Lastabwurf. Wohin und wozu – in [ROADMAP.md](ROADMAP.md).

---

## 📚 Dokumentation

| Dokument | Für wen |
|---|---|
| [AUTOPILOT_GUIDE.md](AUTOPILOT_GUIDE.md) | für Piloten: jeder Modus, jede Funktion und jeder Drehregler, wie man sie auf einen Schalter legt, das Pitotrohr, die Bodenstation |
| [PILOT_GUIDE.md](PILOT_GUIDE.md) | Aufbau, Pinbelegung, Sender, Failsafe, erster Flug |
| [DEVELOPER_GUIDE.md](DEVELOPER_GUIDE.md) | für Entwickler: Dateien, Vorzeichenkonventionen, API, wie man einen Sensor, einen Modus oder ein Board hinzufügt |
| [ARCHITECTURE.md](ARCHITECTURE.md) | Schichten, Tasks, der Regeltakt, Zustandsautomaten |
| [TESTING.md](TESTING.md) | Tests, Simulationen, Abdeckung, Analyse |
| [reference/](reference/README.md) | eine Referenz zu jeder Klasse |
| [FC_BOARD.md](FC_BOARD.md) · [ROADMAP.md](ROADMAP.md) | die Flugsteuerungsplatine · wohin sich das Projekt bewegt |
| [airframe/](airframe/README.md) | die Zelle der Astro-Cargo: Fusion-360-Projekt und STL-Dateien zum Drucken, bekannte Mängel der Version v2 |

> **Verwandtes Projekt:** [esp32-rc-joystick](https://github.com/damir-lebedev/esp32-rc-joystick) – der FS-i6-Sender als USB-Joystick für den Simulator, auf demselben ESP32-S3: erst im Simulator Stunden sammeln, dann im Feld.

---

## 🤝 Mitmachen

Wir brauchen Hände und Köpfe: Aerodynamik und Flugmodellbau, 3D-Druck und Festigkeit, Embedded-C++, Sensoren und Autopiloten, Bodenschnittstellen. Issues und Pull Requests gehen in den Branch `main`; beginnen Sie mit [DEVELOPER_GUIDE.md](DEVELOPER_GUIDE.md).

## 📜 Lizenz

Die [OpenPlane License](LICENSE.md) ist eine Lizenz auf Grundlage der MIT-Lizenz mit zusätzlichen Bedingungen. Code, Dokumentation und Modelldateien dürfen genutzt, kopiert, verändert und verkauft werden, auch in kommerziellen Produkten. Die Bedingungen:

1. **Nennen Sie den Urheber – Damir Lebedev (Damn / Проклятый).** Der Name muss dort stehen, wo die Nutzer Ihres Produkts ihn sehen: in der Dokumentation, in der README oder auf einer „Über“-Seite. Behalten Sie den Lizenztext zusammen mit dem Code bei.
2. **Militärische Nutzung ist verboten.** Das Projekt darf nicht für Armeen und paramilitärische Organisationen, im Krieg oder zum Bau von Waffen, Munition sowie Waffenträger- und Zielsystemen verwendet werden.
3. **Schädigen Sie Menschen und Sachen nicht vorsätzlich ohne ihre vorherige schriftliche Einwilligung in diesen Schaden.** Ihr eigenes Gerät dürfen Sie kaputt machen, wenn es niemanden gefährdet: zum Beispiel mit einer Luftpistole auf die eigene Drohne schießen. Menschen zu verstümmeln oder zu töten ist nicht erlaubt.
4. **Halten Sie Sicherheitsvorschriften und Gesetze ein** – beim Bauen, Testen und Fliegen.

Werden die Bedingungen verletzt, erlischt die Erlaubnis zur Nutzung des Projekts. Wegen der Verbote bestimmter Nutzungen ist dies keine „offene“ Lizenz im Sinne der OSI: Der Code kann gelesen, kopiert und verändert werden, formal ist das Projekt aber Source-available und kein Open Source.

Rechtskraft hat nur der englische Text in der Datei [LICENSE](LICENSE.md): Übersetzungen der Lizenz in andere Sprachen dienen lediglich der Bequemlichkeit.

Die Firmware steuert ein Luftfahrzeug und ist nicht zertifiziert. Alles, was Sie damit tun, geschieht auf eigene Gefahr; der Autor übernimmt keine Haftung.

```text
OpenPlane © 2026 Damir Lebedev (Damn / Проклятый) — https://github.com/damir-lebedev/OpenPlaneProject
```

<p align="center"><i>Der erste Prototyp ging gleich beim ersten Flug zu Bruch – deshalb liegt hier alles offen: Code, Tests, Probleme. Bauen Sie nach, gehen Sie damit ans Limit, reparieren Sie es gemeinsam mit uns.</i></p>

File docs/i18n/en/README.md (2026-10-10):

<!-- i18n-bar:start -->
  <p align="center">
    <a href="../../../README.md">🇷🇺 Читать на русском</a>
    &nbsp;·&nbsp;
    🇬🇧 <b>Read this in English</b>
    &nbsp;·&nbsp;
    <a href="../zh-CN/README.md">🇨🇳 阅读中文版</a>
    &nbsp;·&nbsp;
    <a href="../es/README.md">🇪🇸 Lee esto en español</a>
  </p>
  <p align="center">
    <a href="../hi/README.md">🇮🇳 हिन्दी में पढ़ें</a>
    &nbsp;·&nbsp;
    <a href="../ar/README.md">🇸🇦 اقرأ بالعربية</a>
    &nbsp;·&nbsp;
    <a href="../pt-BR/README.md">🇧🇷 Leia em português</a>
    &nbsp;·&nbsp;
    <a href="../fr/README.md">🇫🇷 Lire en français</a>
  </p>
  <p align="center">
    <a href="../de/README.md">🇩🇪 Auf Deutsch lesen</a>
    &nbsp;·&nbsp;
    <a href="../ja/README.md">🇯🇵 日本語で読む</a>
    &nbsp;·&nbsp;
    <a href="../ko/README.md">🇰🇷 한국어로 읽기</a>
    &nbsp;·&nbsp;
    <a href="../sv/README.md">🇸🇪 Läs på svenska</a>
  </p>
<!-- i18n-bar:end -->

<p align="center"><sub>🌐 Translation of the <a href="../../../README.md">Russian README</a>. The detailed documentation is translated too, and the links below lead to the translated pages. If the translation and the original differ, the original is authoritative. Console messages, screenshots and plots still use Russian labels. The translation was made by AI and has not been checked by native speakers. Please report mistakes to <a href="https://github.com/damir-lebedev">Damir Lebedev</a> or in the <a href="https://github.com/damir-lebedev/OpenPlaneProject/issues">issue tracker</a>.</sub></p>

<p align="center">
  OpenPlane — an open autopilot for airplanes
</p>

<p align="center">
  
  
  
  <br>
  
  
  
  
</p>

<h3 align="center">Switch off the transmitter — and the plane flies home on its own and circles above you.</h3>
<p align="center">This is no cartoon: <b>the entire firmware</b> flies an airplane model in a closed loop — the same iBUS bytes going in, the same PWM coming out.</p>

<p align="center">
  Link lost: the plane returns home by itself and circles
</p>

---

## ⚡ In 30 seconds

| | |
|---|---|
| **What it is** | An open flight controller and autopilot for radio-controlled airplanes. The main board is the STM32H743 (a Pixhawk-class board): on a DevEBox board the firmware is **already up and flown from the transmitter** — [there is a video](#-stm32h743-came-alive-on-the-board), and the sensors are being connected now. The former base is an ESP32-S3 at ~$10, which passed the bench with all the sensors. |
| **What it can do** | 12 flight modes — from stabilization to return-home, GPS circles, hand launch, auto-landing and **thermal soaring**. A pitot tube made of two cheap barometers. MAVLink telemetry to QGroundControl and Mission Planner. |
| **The main trick** | Any switch or knob on the transmitter = any function. **One line** in `Controls.h` — and SwD is no longer RTH but a payload drop. |
| **Why you can trust it** | 387 automated tests (plus 9 on the board itself with a real SD card), 98% of the code under test, 24 "board × sensors" builds with not a single warning, closed-loop simulations of every mode. |
| **Honestly** | So far only manual mode has flown (the first prototype). The STM32H743 has so far been checked only on the bench, without sensors. The autopilot has been verified on the bench, by tests and by simulations, and is waiting for flight trials — [status below](#-honest-status). |

---

## 🎛️ A switch = a function. One line.

```cpp
// include/config/Controls.h
constexpr Binding BINDINGS[] = {
    Bind::modes  (Channels::SWC, MODE_MANUAL, MODE_STABILIZE, MODE_AUTO_TAKEOFF),
    Bind::feature(Channels::SWB, Feature::FLAPS),
    Bind::mode   (Channels::SWD, MODE_RTH),              // home, while switched on
    Bind::knob   (Channels::VRA, Knob::STAB_GAIN),       // "softer / stiffer" right in flight
    Bind::knob   (Channels::VRB, Knob::CRUISE_SPEED),
};
```

Want thermal soaring on SwD instead of RTH? `Bind::mode(Channels::SWD, MODE_SOARING)`. A payload drop on SwB? `Bind::feature(Channels::SWB, Feature::PAYLOAD_DROP)`. Made a mistake — say, put two modes on one switch or took over a stick — **the build will not pass**: the compiler checks the table (`static_assert`). At power-up the aircraft itself prints what is assigned to which switch.

**12 modes · 10 functions · 7 knobs** — all with examples in the [autopilot reference](AUTOPILOT_GUIDE.md).

---

## ✈️ What the autopilot can do

| | Mode | The idea |
|---|---|---|
| 🕹️ | **MANUAL** | control surfaces = sticks, just as without a flight controller |
| 🧭 | **STABILIZE** | the stick sets the angle; let go and the plane levels itself |
| 📏 | **ALT_HOLD** | + holds altitude using the barometer |
| 🌀 | **ACRO** | the stick sets the rotation rate — for aerobatics |
| 🛣️ | **CRUISE** | heading, altitude and speed hold themselves; the sticks only nudge |
| ⭕ | **LOITER** | circles above a GPS point (the radius is set with a knob) |
| 🏠 | **RTH** | home at 40 m and circles overhead; switches on by itself when the link is lost |
| 🛫 | **AUTO_TAKEOFF** | runway takeoff on the pilot's throttle |
| 🤾 | **LAUNCH** | hand launch: the motor starts after the throw, then a climb |
| 🛬 | **AUTO_LAND** | glide and flare near the ground |
| 🦅 | **SOARING** | motor off, finds thermals and circles in them |
| 🆘 | **RESCUE** | "help!": wings level, nose up — out of any spiral |

Plus: geofence, auto-trim for a "crooked" airplane, turn coordination, stall protection using the pitot tube, flaps and an air brake, payload drop, a stabilized camera, and a buzzer that says "find me in the grass".

---

## 📈 Every mode flies — in a closed loop

Not "a function returned a number", but a **flight**: transmitter → iBUS frame → firmware → PWM → control surface deflections → an airplane model with lift, stalls, wind and thermals → sensors → back to the firmware. 14 such flights are part of the ordinary tests (`pio test -e native`).

<p align="center">RTH, LOITER, geofence and link loss — top view</p>

<table>
  <tr>
    <td width="50%">Soaring: gaining altitude in a thermal without the motor</td>
    <td width="50%">Recovery from a bank and from a spiral</td>
  </tr>
  <tr>
    <td>🦅 Found a thermal on its own and gained altitude <b>with the motor off</b> — the total-energy variometer does not mistake "stick back" for an updraft.</td>
    <td>🆘 A 60° bank — and a few seconds later, a level horizon. RESCUE pulls the plane out of a spiral with a 70° bank and a −40° nose.</td>
  </tr>
  <tr>
    <td>Hand launch and auto-landing</td>
    <td>Pitot tube on two barometers</td>
  </tr>
  <tr>
    <td>🤾 Hand throw → the motor starts only once the hand is clear of the propeller → climb. 🛬 Landing: glide and flare at 3 m.</td>
    <td>🌬️ Airspeed from a tube made of two <b>noisy</b> barometers with a 150 Pa offset between the chips — the error is below 0.5 m/s.</td>
  </tr>
</table>

---

## 🌬️ A pitot tube for pennies

A proper airspeed sensor costs about as much as half a flight controller. Here there are **two barometers**: a BMP581 in the tube (total pressure) and the main barometer in the fuselage (static pressure). The firmware zeroes the difference between the chips on the ground, filters, computes air density from altitude and temperature, and notices swapped hoses. What this gives: CRUISE holds **air**speed, not throttle; stall protection; an honest speed in telemetry. The build is described in the [reference](AUTOPILOT_GUIDE.md#a-diy-pitot-tube).

---

## 📡 Ground station: browser or QGroundControl

<table>
  <tr>
    <td width="46%">Web dashboard: sensors, autopilot, navigation</td>
    <td>
      <b>ESP32 — a web dashboard right from the aircraft.</b> Access point <code>OpenPlane-Debug</code>, address <code>192.168.4.1</code>: transmitter channels, outputs, all sensors, mode, navigation, mode changes and PID tuning on the fly. No apps and no extra hardware.<br><br>
      <b>STM32H743 — MAVLink over a radio modem.</b> QGroundControl and Mission Planner see the aircraft as an ArduPilot airplane: horizon, a map with the home point, speed from the pitot tube, modes under their ArduPlane names, PID from the parameters window, mode changes with a button. ARM from the ground is not possible, only with a switch: it is safer that way.<br><br>
      MAVLink frames are checked byte for byte against the reference <code>pymavlink</code>.
    </td>
  </tr>
</table>

---

## 📼 Black box

The board records every flight: IMU at 500 Hz, angles and autopilot decisions, PID, all outputs, sticks, barometer, compass, GPS, battery and events — from ARM and throttle-up until landing, with 10 seconds before the start. **ESP32-S3** records to its built-in flash (13.9 MB, about 11 minutes), **STM32H743** to an SD card (64 MB — about an hour; the card remains an ordinary FAT32 card, and the firmware writes into a pre-created file `BLACKBOX.BIN`). Erasing happens only on the ground. After the flight, `python tools/blackbox.py download` downloads the flight over USB and splits it into CSV files; flights can also be decoded from the SD card without the board: `python tools/blackbox.py ring E:/BLACKBOX.BIN`. Details — [BLACKBOX.md](BLACKBOX.md).

---

## 🔩 Hardware: one firmware — four boards, twelve sensors

| Board | Status | What has been checked |
|---|---|---|
| **STM32H743VIT6** | ✅ main board · 🔧 DevEBox, sensors being connected + 🧪 tests | on the board: boot, console over USB, **SD card and black box** (on-board tests), **iBUS reception, ARM and control of the servos and motor from the transmitter** (the launch is on video); on the PC — the whole firmware: FreeRTOS tasks, flash, MAVLink, I2C and SPI. Sensors have not been connected to the board yet |
| **ESP32-S3 N16R8** | ✅ former main board, on the bench | all sensors, servos, iBUS, OLED, dashboard live; the whole firmware in tests |
| **ESP32 38-pin** | 🧪 tests | the whole firmware in tests with the ICM-45686 kit |
| **ESP32-C3 SuperMini** | ✈️ has flown (manual) | the first prototype; builds of all kits |

| Sensor | What it is | Buses |
|---|---|---|
| **LSM6DSV** + **QMC6309** | IMU + compass (module) | I2C / SPI |
| **ICM-45686** + **QMC6309** | IMU + compass (alternative) | I2C / SPI |
| **SPL06-001** | fuselage barometer | I2C / SPI |
| **BMP581** | main barometer and the pitot tube barometer | I2C / SPI |
| MPU6050/6500, ICM-42688, BMP388, BME280, QMC5883P/L | bench and legacy | I2C / SPI |
| **u-blox M10** | GPS, 10 Hz, UBX | UART |

A sensor is changed with one line (`SENSOR_KIT_LSM6DSV_PITOT`), a board with one build flag. All 4 boards × 6 sensor kits build without warnings: [`tools/build_matrix.sh`](../../../tools/build_matrix.sh).

<table>
  <tr>
    <td width="50%">Bench: ESP32-S3 with all sensors</td>
    <td width="50%">Motor thrust test</td>
  </tr>
  <tr>
    <td>The ESP32-S3 bench: IMU, barometer, compass, OLED, servos, receiver.</td>
    <td>Test of the motor-propeller group.</td>
  </tr>
</table>

### 🎥 STM32H743 came alive on the board

The firmware for the STM32H743 runs on a DevEBox board **without a single sensor** and is flown from an ordinary transmitter: the iBUS receiver, ARM, servos and motor respond to the sticks and switches in manual mode. The whole launch was recorded on video.

▶️ **[Watch the launch on video](https://t.me/lisnmylife/420)**

What this proves: the "transmitter → iBUS → firmware → PWM" chain works on real hardware, not only in tests. What is not yet proven: no sensors (IMU, barometer, GPS) have been connected to this board, so the autopilot modes have not yet been tried on it.

---

## 🧪 Quality you can verify

| | |
|---|---|
| **387 automated tests** | modules, chip drivers checked at the register level, closed-loop flights, the ESP32 and STM32 firmware **in full** on a PC; plus 9 tests on the STM32 board itself with a real SD card |
| **98.3% of lines, 87.7% of branches** | `gcovr` coverage, including the STM32 code |
| **24/24 builds** | 4 boards × 6 sensor kits, `-Wall -Wextra`, zero warnings |
| **0 findings** | cppcheck and clang-tidy over all the code |
| **References, not copies of code** | sensor formulas follow the datasheets (Bosch, ST, TDK, Goertek), MAVLink follows pymavlink |

```bash
pio test -e native -e native-stm32   # all tests, ~1.5 minutes, no hardware needed
```

Details — [TESTING.md](TESTING.md).

---

## 🧠 How it is built

```mermaid
flowchart LR
    RC["Transmitter FS-i6<br/>iBUS"] --> SW["PilotSwitches<br/>Controls.h"]
    SENS["IMU · barometers · compass<br/>GPS · pitot tube"] --> AP
    SW --> AP["Autopilot<br/>12 modes · navigation<br/>failsafe · geofence"]
    AP --> FC["FlightController<br/>ARM · mixer · flaps"]
    FC --> OUT["Servos · ESC<br/>payload · camera"]
    AP -.-> TLM["Wi-Fi dashboard<br/>MAVLink · OLED"]
```

- **Header-only C++**, a single translation unit, no dynamic memory in the flight loop. Prefer `.h/.cpp`? There is a parallel branch for you, [`feature/split-headers`](https://github.com/damir-lebedev/OpenPlaneProject/tree/feature/split-headers): a script generates it from this one, and the firmware with LTO comes out the same size.
- **HAL** — the only layer that knows the MCU: a new board is a new `Board`, not a rewritten autopilot.
- **A sensor driver does not know the bus**: one class works over both I2C and SPI.
- **Safety through order of operations**: link loss > ARM > mode > throttle; no mode can push throttle past ARM.

Details — [ARCHITECTURE.md](ARCHITECTURE.md).

---

## 🚀 Quick start

```bash
pip install platformio
git clone https://github.com/damir-lebedev/OpenPlaneProject && cd OpenPlaneProject
pio run -e stm32h743-devebox -t upload                    # DevEBox H743: USB DFU, console over USB
pio run -e esp32-s3 -t upload && pio device monitor     # ESP32-S3
pio run -e stm32h743 -t upload                            # STM32H743 (ST-Link)
```

DevEBox: the board has no BOOT0 button — before the first upload, connect pin BT0 to 3V3 and press RST; after that, the `D` key in the console reboots the board into the bootloader by itself ([details](DEVELOPER_GUIDE.md#stm32h743)).

In the serial monitor: `h` — menu, `b` — which chips are visible on the buses, `s` — sensors, `p` — output test (remove the propeller!). Then — the [pilot's guide](PILOT_GUIDE.md).

---

## 🟢 Honest status

| What | Where it was verified |
|---|---|
| Manual control, mixer | ✈️ in flight (first prototype, C3) |
| ARM, failsafe, flaps, servos, motor | 🔧 on the bench (S3) |
| STABILIZE | 🔧 on the bench: the control surfaces respond to tilts in the right direction |
| Bench sensors (MPU6500, BMP388, QMC5883P), OLED, dashboard | 🔧 on the bench |
| The other modes, navigation, pitot tube, MAVLink | 🧪 tests and closed-loop simulations |
| New sensors (LSM6DSV, ICM-45686, QMC6309, SPL06, BMP581) | 🧪 register emulators built from the datasheets |
| STM32H743: SD card, black box, console over USB | 🔧 on the DevEBox board (on-board tests) |
| STM32H743: iBUS, ARM, PWM to the servos and motor, manual control | 🔧 on the board without sensors, recorded on video |
| STM32H743: sensors (IMU, barometer, compass, GPS) and autopilot modes | 🧪 the whole firmware on a PC; no sensors connected to the board yet |

The airplane model in the simulations is simplified, and the coefficients are starting values. Every new mode is first tried at altitude, with a finger on the MANUAL switch.

---

## 🗺️ Roadmap

- [x] Manual control, ARM, failsafe, object-oriented firmware, web dashboard
- [x] ESP32-S3 bench with all sensors — live
- [x] 12 modes, GPS navigation, RTH on link loss, geofence
- [x] Switches and knobs in one line, payload drop, camera, auto-trim
- [x] Pitot tube from two barometers, stall protection
- [x] New sensors: LSM6DSV, ICM-45686, QMC6309, SPL06, BMP581
- [x] STM32H743: full firmware, MAVLink, settings in flash
- [x] Closed-loop simulations of all modes, the whole firmware in tests
- [x] Black box: flights to flash (ESP32-S3) and to an SD card (STM32H743), download and decoding to CSV
- [x] STM32H743 runs on the board: transmitter → iBUS → servos and motor (no sensors, on video)
- [ ] STM32H743: connect the sensors and go through the bench the same way as with the ESP32-S3
- [ ] Flight trials of the autopilot on the new airframe
- [ ] A custom flight controller board ([FC_BOARD.md](FC_BOARD.md)) on the STM32H743
- [ ] Waypoint flight, MAVLink missions
- [ ] Adaptive feedback (a draft is already verified in simulation)
- [ ] Current and battery sensor, telemetry to the transmitter (iBUS-SENS)
- [ ] Autonomous delivery: route → payload drop → home

Details — [ROADMAP.md](ROADMAP.md).

---

## 💼 For partners and investors

Small delivery airplanes and monitoring aircraft are either closed, expensive platforms or scattered hobby projects. OpenPlane aims at the middle: **an open, verifiable autopilot on mass-market hardware**, where every function is covered by tests and can be adapted to a task — delivering medicines to hard-to-reach places, monitoring fields and forests, search operations.

What has already been done with our own resources: an architecture that moves between boards without being rewritten; an autopilot with a full set of modes; test infrastructure on which new features appear quickly and do not break old ones. What additional resources would speed up: flight trials, a custom flight controller board on the STM32H743, waypoint flight and payload drop. Where and why — [ROADMAP.md](ROADMAP.md).

---

## 📚 Documentation

| Document | For whom |
|---|---|
| [AUTOPILOT_GUIDE.md](AUTOPILOT_GUIDE.md) | the pilot: every mode, function and knob, how to put them on a switch, the pitot tube, the ground station |
| [PILOT_GUIDE.md](PILOT_GUIDE.md) | assembly, pinout, transmitter, failsafe, first flight |
| [DEVELOPER_GUIDE.md](DEVELOPER_GUIDE.md) | the developer: files, sign conventions, API, how to add a sensor, a mode or a board |
| [ARCHITECTURE.md](ARCHITECTURE.md) | layers, tasks, the control tick, state machines |
| [TESTING.md](TESTING.md) | tests, simulations, coverage, analysis |
| [reference/](reference/README.md) | a reference for every class |
| [FC_BOARD.md](FC_BOARD.md) · [ROADMAP.md](ROADMAP.md) | the flight controller board · where the project is heading |
| [airframe/](airframe/README.md) | the Astro-Cargo airframe: Fusion 360 project and STL files for printing, known flaws of version v2 |

> **Related project:** [esp32-rc-joystick](https://github.com/damir-lebedev/esp32-rc-joystick) — the FS-i6 transmitter as a USB joystick for a simulator, on the same ESP32-S3: first log your hours in the simulator, then in the field.

---

## 🤝 Contributing

We need hands and heads: aerodynamics and aeromodelling, 3D printing and structural strength, embedded C++, sensors and autopilots, ground interfaces. Issues and pull requests go to the `main` branch; start with [DEVELOPER_GUIDE.md](DEVELOPER_GUIDE.md).

## 📜 License

The [OpenPlane License](../../../LICENSE) is a license based on MIT with additional conditions. The code, the documentation and the model files may be used, copied, modified and sold, including in commercial products. The conditions are:

1. **Credit the author — Damir Lebedev (Damn / Проклятый).** The name must appear where the users of your product will see it: in the documentation, the README or an "About" page. Keep the license text together with the code.
2. **Military use is prohibited.** The project must not be used by armies and paramilitary organizations, in war, or to create weapons, munitions, and delivery or targeting systems.
3. **Do not intentionally harm people or property without their prior written consent to that harm.** You may break your own equipment if it threatens no one: for example, shooting your own drone with an air pistol. Maiming and killing people is not allowed.
4. **Follow the safety rules and the law** when building, testing and flying.

If the conditions are violated, the permission to use the project ends. Because of the bans on certain kinds of use, this is not an "open" license in the OSI sense: the code is available to read, copy and modify, but formally the project is source-available, not open source.

Only the English text in the [LICENSE](../../../LICENSE) file has legal force: translations of the license into other languages are provided for convenience.

The firmware controls an aircraft and is not certified. Whatever you do with it is at your own risk; the author accepts no liability.

```text
OpenPlane © 2026 Damir Lebedev (Damn / Проклятый) — https://github.com/damir-lebedev/OpenPlaneProject
```

<p align="center"><i>The first prototype broke on its very first flight — which is why everything here is in the open: code, tests, problems. Build it, break it, fix it together with us.</i></p>

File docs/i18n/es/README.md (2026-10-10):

<!-- i18n-bar:start -->
  <p align="center">
    <a href="../../../README.md">🇷🇺 Читать на русском</a>
    &nbsp;·&nbsp;
    <a href="../en/README.md">🇬🇧 Read this in English</a>
    &nbsp;·&nbsp;
    <a href="../zh-CN/README.md">🇨🇳 阅读中文版</a>
    &nbsp;·&nbsp;
    🇪🇸 <b>Lee esto en español</b>
  </p>
  <p align="center">
    <a href="../hi/README.md">🇮🇳 हिन्दी में पढ़ें</a>
    &nbsp;·&nbsp;
    <a href="../ar/README.md">🇸🇦 اقرأ بالعربية</a>
    &nbsp;·&nbsp;
    <a href="../pt-BR/README.md">🇧🇷 Leia em português</a>
    &nbsp;·&nbsp;
    <a href="../fr/README.md">🇫🇷 Lire en français</a>
  </p>
  <p align="center">
    <a href="../de/README.md">🇩🇪 Auf Deutsch lesen</a>
    &nbsp;·&nbsp;
    <a href="../ja/README.md">🇯🇵 日本語で読む</a>
    &nbsp;·&nbsp;
    <a href="../ko/README.md">🇰🇷 한국어로 읽기</a>
    &nbsp;·&nbsp;
    <a href="../sv/README.md">🇸🇪 Läs på svenska</a>
  </p>
<!-- i18n-bar:end -->

<p align="center"><sub>🌐 Traducción del <a href="../../../README.md">README en ruso</a>. La documentación detallada también está traducida y los enlaces de abajo llevan a las páginas traducidas. Si la traducción y el original difieren, prevalece el original. Los mensajes de la consola, las capturas y los gráficos siguen mostrando textos en ruso. La traducción la ha hecho una IA y no la han revisado hablantes nativos. Si encuentras errores, escribe a <a href="https://github.com/damir-lebedev">Damir Lebedev</a> o abre una <a href="https://github.com/damir-lebedev/OpenPlaneProject/issues">incidencia</a>.</sub></p>

<p align="center">
  OpenPlane — piloto automático abierto para aviones
</p>

<p align="center">
  
  
  
  <br>
  
  
  
  
</p>

<h3 align="center">Apagas la emisora: el avión vuelve solo a casa y da vueltas sobre tu cabeza.</h3>
<p align="center">Esto no es un dibujo animado: <b>todo el firmware</b> pilota un modelo de avión en lazo cerrado, con los mismos bytes iBUS a la entrada y el mismo PWM a la salida.</p>

<p align="center">
  Pérdida de señal: el avión vuelve solo a casa y da vueltas
</p>

---

## ⚡ En 30 segundos

| | |
|---|---|
| **Qué es** | Un controlador de vuelo y piloto automático abiertos para aviones de radiocontrol. La placa principal es la STM32H743 (una placa de la clase Pixhawk): en una placa DevEBox el firmware **ya está en marcha y se pilota con la emisora** ([hay vídeo](#-la-stm32h743-cobra-vida-en-la-placa)), y ahora se están conectando los sensores. La base anterior es un ESP32-S3 de unos 10 $, que pasó el banco con todos los sensores. |
| **Qué hace** | 12 modos de vuelo: desde la estabilización hasta el regreso a casa, círculos por GPS, lanzamiento a mano, aterrizaje automático y **vuelo a vela en térmicas**. Un tubo de Pitot hecho con dos barómetros baratos. Telemetría MAVLink para QGroundControl y Mission Planner. |
| **Lo principal** | Cualquier interruptor o potenciómetro de la emisora = cualquier función. **Una línea** en `Controls.h` y SwD deja de ser RTH para convertirse en lanzamiento de carga. |
| **Por qué fiarse** | 387 pruebas automáticas (y 9 más en la propia placa, con una tarjeta SD real), el 98 % del código cubierto por pruebas, 24 compilaciones «placa × sensores» sin un solo aviso y simulaciones en lazo cerrado de cada modo. |
| **Con honestidad** | De momento solo ha volado el modo manual (el primer prototipo). La STM32H743 solo se ha probado en el banco, sin sensores. El piloto automático se ha verificado en el banco, con pruebas y con simulaciones, y está a la espera de los ensayos en vuelo: [estado más abajo](#-estado-real). |

---

## 🎛️ Un interruptor = una función. Una línea.

```cpp
// include/config/Controls.h
constexpr Binding BINDINGS[] = {
    Bind::modes  (Channels::SWC, MODE_MANUAL, MODE_STABILIZE, MODE_AUTO_TAKEOFF),
    Bind::feature(Channels::SWB, Feature::FLAPS),
    Bind::mode   (Channels::SWD, MODE_RTH),              // a casa, mientras esté activado
    Bind::knob   (Channels::VRA, Knob::STAB_GAIN),       // «más suave / más duro» en pleno vuelo
    Bind::knob   (Channels::VRB, Knob::CRUISE_SPEED),
};
```

¿Quieres el vuelo a vela en térmicas en SwD en lugar de RTH? `Bind::mode(Channels::SWD, MODE_SOARING)`. ¿Lanzamiento de carga en SwB? `Bind::feature(Channels::SWB, Feature::PAYLOAD_DROP)`. Si te equivocas (por ejemplo, si asignas dos modos al mismo interruptor o te quedas con un stick), **la compilación no pasará**: la tabla la comprueba el compilador (`static_assert`). Al encenderse, el avión imprime por sí mismo qué hay en cada interruptor.

**12 modos · 10 funciones · 7 potenciómetros**, todo con ejemplos en la [referencia del piloto automático](AUTOPILOT_GUIDE.md).

---

## ✈️ Qué sabe hacer el piloto automático

| | Modo | En esencia |
|---|---|---|
| 🕹️ | **MANUAL** | superficies de control = sticks, como sin controlador de vuelo |
| 🧭 | **STABILIZE** | el stick fija el ángulo; lo sueltas y el avión se nivela solo |
| 📏 | **ALT_HOLD** | + mantiene la altitud con el barómetro |
| 🌀 | **ACRO** | el stick fija la velocidad de giro, para acrobacia |
| 🛣️ | **CRUISE** | rumbo, altitud y velocidad se mantienen solos; los sticks solo corrigen |
| ⭕ | **LOITER** | círculos sobre un punto GPS (el radio se ajusta con un potenciómetro) |
| 🏠 | **RTH** | a casa a 40 m y círculos sobre tu cabeza; se activa solo si se pierde la señal |
| 🛫 | **AUTO_TAKEOFF** | despegue desde la pista con el acelerador del piloto |
| 🤾 | **LAUNCH** | lanzamiento a mano: el motor arranca tras el lanzamiento y comienza el ascenso |
| 🛬 | **AUTO_LAND** | planeo y recogida cerca del suelo |
| 🦅 | **SOARING** | motor apagado; encuentra térmicas y da vueltas en ellas |
| 🆘 | **RESCUE** | «¡socorro!»: alas niveladas y morro arriba, desde cualquier espiral |

Además: geovalla, autotrim para un avión «torcido», coordinación de virajes, protección contra la pérdida de sustentación con el tubo de Pitot, flaps y aerofreno, lanzamiento de carga, cámara estabilizada y un zumbador de «búscame en la hierba».

---

## 📈 Cada modo vuela, en lazo cerrado

No es «una función devolvió un número», sino un **vuelo**: emisora → trama iBUS → firmware → PWM → deflexión de las superficies de control → modelo de avión con sustentación, pérdida, viento y térmicas → sensores → de nuevo el firmware. 14 vuelos así forman parte de las pruebas habituales (`pio test -e native`).

<p align="center">RTH, LOITER, geovalla y pérdida de señal: vista desde arriba</p>

<table>
  <tr>
    <td width="50%">Vuelo a vela: ganancia de altura en una térmica sin motor</td>
    <td width="50%">Recuperación de un alabeo y de una espiral</td>
  </tr>
  <tr>
    <td>🦅 Encontró una térmica por sí solo y ganó altura <b>con el motor apagado</b>: el variómetro de energía total no confunde «stick atrás» con una corriente ascendente.</td>
    <td>🆘 Alabeo de 60° y, unos segundos después, horizonte nivelado. RESCUE saca al avión de una espiral con 70° de alabeo y −40° de morro.</td>
  </tr>
  <tr>
    <td>Lanzamiento a mano y aterrizaje automático</td>
    <td>Tubo de Pitot con dos barómetros</td>
  </tr>
  <tr>
    <td>🤾 Lanzamiento a mano → el motor arranca solo cuando la mano se ha alejado de la hélice → ascenso. 🛬 Aterrizaje: planeo y recogida a 3 m.</td>
    <td>🌬️ Velocidad del aire con un tubo hecho de dos barómetros <b>ruidosos</b>, con un desfase de 150 Pa entre los chips: el error es inferior a 0.5 m/s.</td>
  </tr>
</table>

---

## 🌬️ Un tubo de Pitot por cuatro duros

Un buen sensor de velocidad del aire cuesta como la mitad de un controlador de vuelo. Aquí hay **dos barómetros**: un BMP581 en el tubo (presión total) y el barómetro principal en el fuselaje (presión estática). El firmware pone a cero en tierra la diferencia entre los chips, filtra, calcula la densidad del aire a partir de la altitud y la temperatura y detecta si las mangueras están intercambiadas. Qué se consigue: CRUISE mantiene la velocidad **del aire**, no el acelerador; protección contra la pérdida de sustentación; una velocidad fiable en la telemetría. El montaje se explica en la [referencia](AUTOPILOT_GUIDE.md#un-tubo-de-pitot-casero).

---

## 📡 Estación de tierra: navegador o QGroundControl

<table>
  <tr>
    <td width="46%">Panel web: sensores, piloto automático, navegación</td>
    <td>
      <b>ESP32: un panel web directamente desde el avión.</b> Punto de acceso <code>OpenPlane-Debug</code>, dirección <code>192.168.4.1</code>: canales de la emisora, salidas, todos los sensores, modo, navegación, cambio de modo y ajuste del PID sobre la marcha. Sin aplicaciones ni hardware adicional.<br><br>
      <b>STM32H743: MAVLink por radiomódem.</b> QGroundControl y Mission Planner ven el avión como un avión ArduPilot: horizonte, mapa con el punto de origen, velocidad según el tubo de Pitot, modos con los nombres de ArduPlane, PID desde la ventana de parámetros y cambio de modo con un botón. El ARM desde tierra no es posible, solo con un interruptor: es más seguro.<br><br>
      Las tramas MAVLink se han comparado byte a byte con la referencia <code>pymavlink</code>.
    </td>
  </tr>
</table>

---

## 📼 Caja negra

La placa graba cada vuelo: IMU a 500 Hz, ángulos y decisiones del piloto automático, PID, todas las salidas, sticks, barómetro, brújula, GPS, batería y eventos, desde el ARM y el acelerador hasta el aterrizaje, con 10 segundos antes del inicio. La **ESP32-S3** graba en su flash integrada (13.9 MB, unos 11 minutos); la **STM32H743**, en una tarjeta SD (64 MB, aproximadamente una hora; la tarjeta sigue siendo una FAT32 normal y el firmware escribe en un archivo creado de antemano, `BLACKBOX.BIN`). El borrado solo se hace en tierra. Después del vuelo, `python tools/blackbox.py download` descarga el vuelo por USB y lo desglosa en CSV; los vuelos de la tarjeta SD también se pueden descodificar sin la placa: `python tools/blackbox.py ring E:/BLACKBOX.BIN`. Más detalles: [BLACKBOX.md](BLACKBOX.md).

---

## 🔩 Hardware: un firmware, cuatro placas, doce sensores

| Placa | Estado | Qué se ha comprobado |
|---|---|---|
| **STM32H743VIT6** | ✅ principal · 🔧 DevEBox, conectando sensores + 🧪 pruebas | en la placa: arranque, consola por USB, **tarjeta SD y caja negra** (pruebas en la placa), **recepción iBUS, ARM y control de servos y motor desde la emisora** (el arranque está en vídeo); en el PC, todo el firmware: tareas FreeRTOS, flash, MAVLink, I2C y SPI. Aún no se han conectado sensores a la placa |
| **ESP32-S3 N16R8** | ✅ antigua principal, en el banco | todos los sensores, servos, iBUS, OLED y panel web en vivo; el firmware completo, en pruebas |
| **ESP32 38-pin** | 🧪 pruebas | el firmware completo en pruebas con el kit ICM-45686 |
| **ESP32-C3 SuperMini** | ✈️ ha volado (manual) | el primer prototipo; compilación de todos los kits |

| Sensor | Qué es | Buses |
|---|---|---|
| **LSM6DSV** + **QMC6309** | IMU + brújula (módulo) | I2C / SPI |
| **ICM-45686** + **QMC6309** | IMU + brújula (alternativa) | I2C / SPI |
| **SPL06-001** | barómetro del fuselaje | I2C / SPI |
| **BMP581** | barómetro principal y barómetro del tubo de Pitot | I2C / SPI |
| MPU6050/6500, ICM-42688, BMP388, BME280, QMC5883P/L | de banco y anteriores | I2C / SPI |
| **u-blox M10** | GPS, 10 Hz, UBX | UART |

El sensor se cambia con una sola línea (`SENSOR_KIT_LSM6DSV_PITOT`) y la placa, con una sola opción de compilación. Las 4 placas × 6 kits de sensores se compilan sin avisos: [`tools/build_matrix.sh`](../../../tools/build_matrix.sh).

<table>
  <tr>
    <td width="50%">Banco: ESP32-S3 con todos los sensores</td>
    <td width="50%">Prueba de empuje del motor</td>
  </tr>
  <tr>
    <td>Banco con la ESP32-S3: IMU, barómetro, brújula, OLED, servos, receptor.</td>
    <td>Prueba del grupo motor-hélice.</td>
  </tr>
</table>

### 🎥 La STM32H743 cobra vida en la placa

El firmware de la STM32H743 se ejecuta en una placa DevEBox **sin un solo sensor** y se pilota con una emisora normal: el receptor iBUS, el ARM, los servos y el motor responden a los sticks y a los interruptores en modo manual. Todo el arranque quedó grabado en vídeo.

▶️ **[Ver el arranque en vídeo](https://t.me/lisnmylife/420)**

Lo que esto demuestra: la cadena «emisora → iBUS → firmware → PWM» funciona en hardware real y no solo en las pruebas. Lo que aún no está demostrado: a esta placa no se le han conectado sensores (IMU, barómetro, GPS), así que los modos del piloto automático todavía no se han probado en ella.

---

## 🧪 Calidad que se puede comprobar

| | |
|---|---|
| **387 pruebas automáticas** | módulos, controladores comprobados a nivel de registros del chip, vuelos en lazo cerrado, el firmware de ESP32 y STM32 **completo** en el PC; además, 9 pruebas en la propia placa STM32 con una tarjeta SD real |
| **98.3 % de líneas, 87.7 % de ramas** | cobertura de `gcovr`, incluido el código de STM32 |
| **24/24 compilaciones** | 4 placas × 6 kits de sensores, `-Wall -Wextra`, cero avisos |
| **0 observaciones** | cppcheck y clang-tidy sobre todo el código |
| **Referencias, no copias de código** | las fórmulas de los sensores siguen las hojas de datos (Bosch, ST, TDK, Goertek) y MAVLink sigue pymavlink |

```bash
pio test -e native -e native-stm32   # todas las pruebas, ~1.5 minutos, sin hardware
```

Más detalles: [TESTING.md](TESTING.md).

---

## 🧠 Cómo está hecho

```mermaid
flowchart LR
    RC["Emisora FS-i6<br/>iBUS"] --> SW["PilotSwitches<br/>Controls.h"]
    SENS["IMU · barómetros · brújula<br/>GPS · tubo de Pitot"] --> AP
    SW --> AP["Autopilot<br/>12 modos · navegación<br/>failsafe · geovalla"]
    AP --> FC["FlightController<br/>ARM · mezclador · flaps"]
    FC --> OUT["Servos · ESC<br/>carga · cámara"]
    AP -.-> TLM["Panel Wi-Fi<br/>MAVLink · OLED"]
```

- **C++ solo con cabeceras (header-only)**, una única unidad de traducción, sin memoria dinámica en el lazo de vuelo. ¿Prefieres `.h/.cpp`? Para ti hay una rama paralela, [`feature/split-headers`](https://github.com/damir-lebedev/OpenPlaneProject/tree/feature/split-headers): se genera desde esta con un script, y el firmware con LTO ocupa lo mismo.
- **HAL**: la única capa que conoce el microcontrolador; una placa nueva es un `Board` nuevo, no un piloto automático reescrito.
- **El controlador de un sensor no conoce el bus**: una misma clase funciona tanto por I2C como por SPI.
- **La seguridad, por el orden de las operaciones**: pérdida de señal > ARM > modo > acelerador; ningún modo puede pasar el acelerador por encima del ARM.

Más detalles: [ARCHITECTURE.md](ARCHITECTURE.md).

---

## 🚀 Inicio rápido

```bash
pip install platformio
git clone https://github.com/damir-lebedev/OpenPlaneProject && cd OpenPlaneProject
pio run -e stm32h743-devebox -t upload                    # DevEBox H743: USB DFU, consola por USB
pio run -e esp32-s3 -t upload && pio device monitor     # ESP32-S3
pio run -e stm32h743 -t upload                            # STM32H743 (ST-Link)
```

DevEBox: la placa no tiene botón BOOT0; antes de la primera carga, une el pin BT0 con 3V3 y pulsa RST. Después, la tecla `D` de la consola reinicia la placa en el cargador de arranque por sí sola ([más detalles](DEVELOPER_GUIDE.md#stm32h743)).

En el monitor serie: `h`, menú; `b`, qué chips se ven en los buses; `s`, sensores; `p`, prueba de las salidas (¡quita la hélice!). Después, la [guía del piloto](PILOT_GUIDE.md).

---

## 🟢 Estado real

| Qué | Dónde se ha comprobado |
|---|---|
| Control manual, mezclador | ✈️ en vuelo (primer prototipo, C3) |
| ARM, failsafe, flaps, servos, motor | 🔧 en el banco (S3) |
| STABILIZE | 🔧 en el banco: las superficies de control responden a las inclinaciones en el sentido correcto |
| Sensores del banco (MPU6500, BMP388, QMC5883P), OLED, panel web | 🔧 en el banco |
| Resto de modos, navegación, tubo de Pitot, MAVLink | 🧪 pruebas y simulaciones en lazo cerrado |
| Sensores nuevos (LSM6DSV, ICM-45686, QMC6309, SPL06, BMP581) | 🧪 emuladores de registros según las hojas de datos |
| STM32H743: tarjeta SD, caja negra, consola por USB | 🔧 en la placa DevEBox (pruebas en la placa) |
| STM32H743: iBUS, ARM, PWM a servos y motor, control manual | 🔧 en la placa sin sensores, grabado en vídeo |
| STM32H743: sensores (IMU, barómetro, brújula, GPS) y modos del piloto automático | 🧪 todo el firmware en el PC; aún no hay sensores conectados a la placa |

El modelo de avión de las simulaciones está simplificado y los coeficientes son valores iniciales. Cada modo nuevo se prueba primero en altura, con el dedo sobre el interruptor MANUAL.

---

## 🗺️ Hoja de ruta

- [x] Control manual, ARM, failsafe, firmware orientado a objetos, panel web
- [x] Banco con la ESP32-S3 y todos los sensores, en vivo
- [x] 12 modos, navegación por GPS, RTH al perder la señal, geovalla
- [x] Interruptores y potenciómetros en una línea, lanzamiento de carga, cámara, autotrim
- [x] Tubo de Pitot con dos barómetros, protección contra la pérdida de sustentación
- [x] Sensores nuevos: LSM6DSV, ICM-45686, QMC6309, SPL06, BMP581
- [x] STM32H743: firmware completo, MAVLink, ajustes en la flash
- [x] Simulaciones en lazo cerrado de todos los modos, todo el firmware en las pruebas
- [x] Caja negra: vuelos en la flash (ESP32-S3) y en una tarjeta SD (STM32H743), descarga y descodificación a CSV
- [x] La STM32H743 funciona en la placa: emisora → iBUS → servos y motor (sin sensores, en vídeo)
- [ ] STM32H743: conectar los sensores y pasar el banco igual que con la ESP32-S3
- [ ] Ensayos en vuelo del piloto automático con el nuevo avión
- [ ] Una placa de controlador de vuelo propia ([FC_BOARD.md](FC_BOARD.md)) con la STM32H743
- [ ] Vuelo por puntos de ruta, misiones MAVLink
- [ ] Realimentación adaptativa (el prototipo ya está verificado en simulación)
- [ ] Sensor de corriente y de batería, telemetría a la emisora (iBUS-SENS)
- [ ] Reparto autónomo: ruta → lanzamiento de carga → casa

Más detalles: [ROADMAP.md](ROADMAP.md).

---
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

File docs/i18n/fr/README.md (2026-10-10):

<!-- i18n-bar:start -->
  <p align="center">
    <a href="../../../README.md">🇷🇺 Читать на русском</a>
    &nbsp;·&nbsp;
    <a href="../en/README.md">🇬🇧 Read this in English</a>
    &nbsp;·&nbsp;
    <a href="../zh-CN/README.md">🇨🇳 阅读中文版</a>
    &nbsp;·&nbsp;
    <a href="../es/README.md">🇪🇸 Lee esto en español</a>
  </p>
  <p align="center">
    <a href="../hi/README.md">🇮🇳 हिन्दी में पढ़ें</a>
    &nbsp;·&nbsp;
    <a href="../ar/README.md">🇸🇦 اقرأ بالعربية</a>
    &nbsp;·&nbsp;
    <a href="../pt-BR/README.md">🇧🇷 Leia em português</a>
    &nbsp;·&nbsp;
    🇫🇷 <b>Lire en français</b>
  </p>
  <p align="center">
    <a href="../de/README.md">🇩🇪 Auf Deutsch lesen</a>
    &nbsp;·&nbsp;
    <a href="../ja/README.md">🇯🇵 日本語で読む</a>
    &nbsp;·&nbsp;
    <a href="../ko/README.md">🇰🇷 한국어로 읽기</a>
    &nbsp;·&nbsp;
    <a href="../sv/README.md">🇸🇪 Läs på svenska</a>
  </p>
<!-- i18n-bar:end -->

<p align="center"><sub>🌐 Traduction du <a href="../../../README.md">README en russe</a>. La documentation détaillée est elle aussi traduite, et les liens ci-dessous mènent aux pages traduites. En cas de divergence entre la traduction et l’original, c’est l’original qui fait foi. Les messages de la console, les captures d’écran et les graphiques portent encore des textes en russe. La traduction a été réalisée par une IA et n’a pas été relue par des locuteurs natifs. Pour signaler une erreur, écrivez à <a href="https://github.com/damir-lebedev">Damir Lebedev</a> ou ouvrez un <a href="https://github.com/damir-lebedev/OpenPlaneProject/issues">ticket</a>.</sub></p>
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

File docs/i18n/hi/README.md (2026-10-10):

<!-- i18n-bar:start -->
  <p align="center">
    <a href="../../../README.md">🇷🇺 Читать на русском</a>
    &nbsp;·&nbsp;
    <a href="../en/README.md">🇬🇧 Read this in English</a>
    &nbsp;·&nbsp;
    <a href="../zh-CN/README.md">🇨🇳 阅读中文版</a>
    &nbsp;·&nbsp;
    <a href="../es/README.md">🇪🇸 Lee esto en español</a>
  </p>
  <p align="center">
    🇮🇳 <b>हिन्दी में पढ़ें</b>
    &nbsp;·&nbsp;
    <a href="../ar/README.md">🇸🇦 اقرأ بالعربية</a>
    &nbsp;·&nbsp;
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

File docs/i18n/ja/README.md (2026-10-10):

<!-- i18n-bar:start -->
  <p align="center">
    <a href="../../../README.md">🇷🇺 Читать на русском</a>
    &nbsp;·&nbsp;
    <a href="../en/README.md">🇬🇧 Read this in English</a>
    &nbsp;·&nbsp;
    <a href="../zh-CN/README.md">🇨🇳 阅读中文版</a>
    &nbsp;·&nbsp;
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

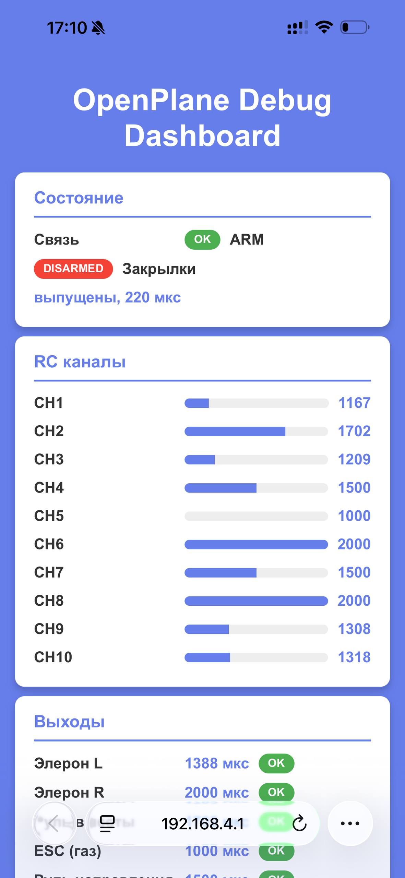
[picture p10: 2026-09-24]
docs/images/web-dashboard-flaps.jpg

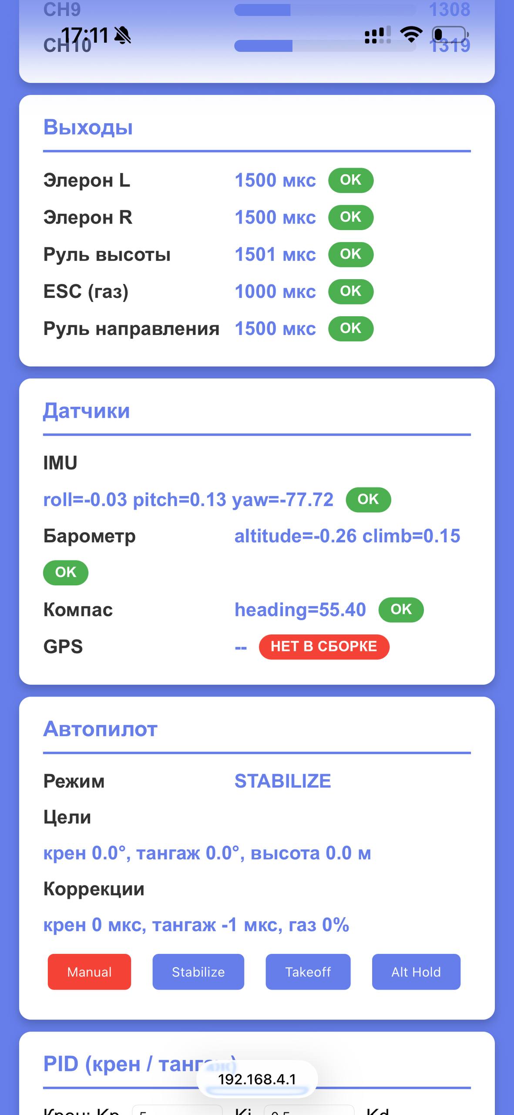
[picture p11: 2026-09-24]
docs/images/web-dashboard-sensors.jpg

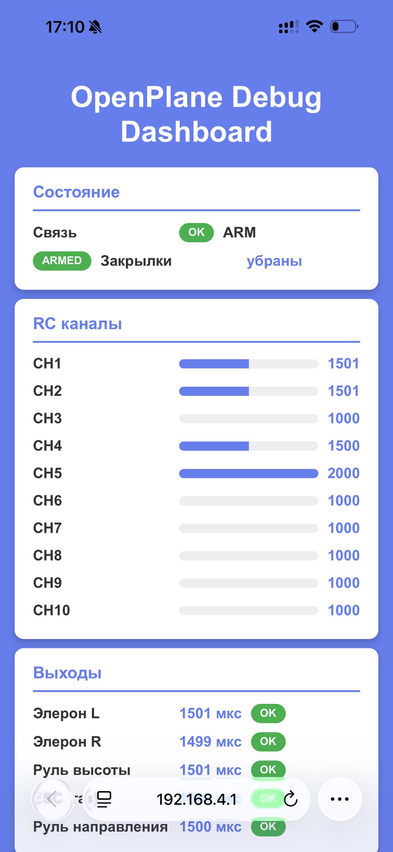
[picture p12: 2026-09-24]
docs/images/web-dashboard-armed.jpg

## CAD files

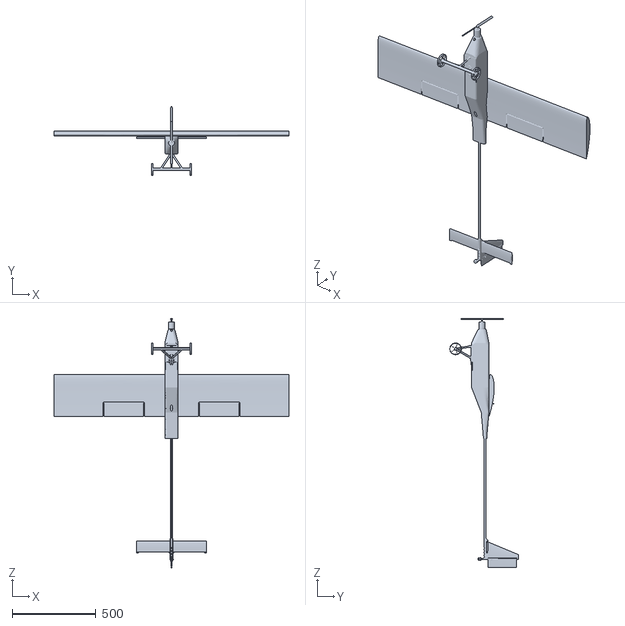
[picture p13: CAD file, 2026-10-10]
airframe/stl/Astro-Cargo v3 (Bad back wheel, gears fixed, battery mount too).stl
1400.0 x 409.0 x 1485.0

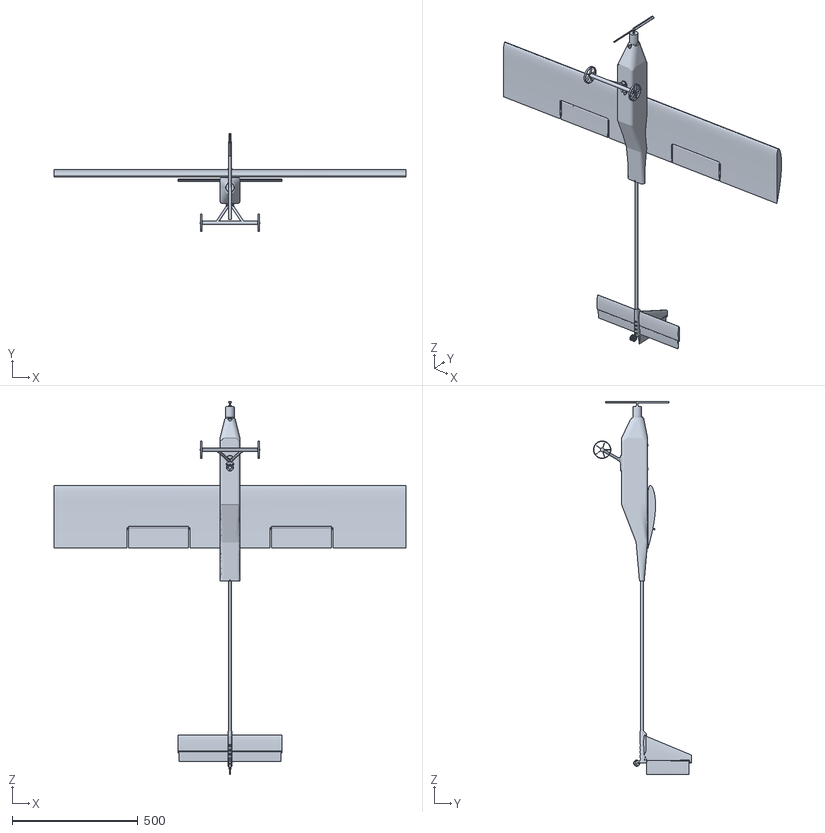
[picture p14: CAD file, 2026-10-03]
airframe/stl/Astro-Cargo v2 (Bad wheel & no battery mount).stl
1400.0 x 391.0 x 1485.0

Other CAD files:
airframe/fusion360/Astro-Cargo v2 (Bad wheel & no battery mount).f3d
airframe/fusion360/Astro-Cargo v3 (Bad back wheel, gears fixed, battery mount too).f3d

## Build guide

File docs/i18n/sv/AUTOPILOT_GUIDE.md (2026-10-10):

# Referens för OpenPlanes autopilot

> 🌐 Den här sidan är en översättning av [det ryska originalet](../../AUTOPILOT_GUIDE.md). Om översättningen och originalet skiljer sig åt gäller originalet. Firmwaren skriver ut sina konsolmeddelanden på ryska, så de citeras oförändrade. Översättningen är gjord av AI och har inte granskats av personer med svenska som modersmål. Rapportera fel till [Damir Lebedev](https://github.com/damir-lebedev) eller i [ärendehanteraren](https://github.com/damir-lebedev/OpenPlaneProject/issues).

Vad autopiloten kan, hur man slår på varje funktion och hur man lägger den på vilken brytare eller ratt som helst på sändaren **med en enda rad**.

> Ärligheten först. Alla lägen har verifierats med enhetstester och flygsimuleringar i sluten slinga (`test/native/test_sim`: hela firmwaren flyger en flygplansmodell). Modellen är förenklad, och koefficienterna i `Config.h` är startvärden: **prova varje läge först på minst 50 m höjd med fingret på MANUAL-brytaren**. Hittills har bara manuellt läge flugits (den första prototypen, med en ESP32-C3); stabiliseringen har verifierats på bänken – ytorna reagerar på lutning åt rätt håll. STM32H743-kortet byggs och klarar samma tester; på riktig hårdvara har DevEBox-kortet verifierats utan sensorer: SD-kortet, den svarta lådan och manuell styrning av servon och motor från sändaren (inspelat på video); inga sensorer har ännu anslutits till det, och autopilotlägena har inte provats på det.

---

## Innehåll

1. [Hur det fungerar på en minut](#hur-det-fungerar-på-en-minut)
2. [Standardfördelning på sändaren](#standardfördelning-på-sändaren)
3. [Tilldela en funktion med en enda rad](#tilldela-en-funktion-med-en-enda-rad)
4. [Lägen](#lägen)
5. [Funktioner (brytare)](#funktioner-brytare)
6. [Rattar](#rattar)
7. [Förlorad förbindelse, geofence, hem](#förlorad-förbindelse-geofence-hem)
8. [Ett hemmabyggt pitotrör](#ett-hemmabyggt-pitotrör)
9. [Markstation: Wi-Fi-panel och MAVLink](#markstation-wi-fi-panel-och-mavlink)
10. [Inställning av ett nytt flygplan, steg för steg](#inställning-av-ett-nytt-flygplan-steg-för-steg)
11. [Autopilotens kontroll före flygning](#autopilotens-kontroll-före-flygning)
12. [Vad varje läge behöver](#vad-varje-läge-behöver)

---

## Hur det fungerar på en minut

```
spakar  ─┐
         ├─► PilotSwitches (config/Controls.h) ─► läge, funktioner, rattar
brytare ─┘                                              │
                                                        ▼
sensorer (IMU, barometer, kompass, GPS, pitotrör) ─► Autopilot ─► roder- och gaskommandon
                                                        │
                           FlightController: klaffar, last, kamera, summer, failsafe
                                                        ▼
                                    skevroder · höjdroder · sidroder · ESC · AUX1 · AUX2
```

- **Läget** avgör vem som flyger: piloten (MANUAL), piloten med en hjälpreda (STABILIZE, ALT_HOLD, ACRO), autopiloten med pilotens korrigeringar (CRUISE, LOITER, RTH…).
- **Funktioner** slås på ovanpå vilket läge som helst: klaffar, broms, lastsläpp, geofence…
- **Rattar** ändrar ett tal steglöst: stabiliseringens styrka, marschfart, cirkelradie…
- I lägena med stabilisering **anger spaken vinkeln**, inte roderutslaget: släpp spaken så rätar flygplanet upp sig självt.
- Ett sensorfel ”rycker” aldrig i flygplanet: ingen IMU – ytorna stannar hos piloten; ingen barometer – piloten håller höjden; ingen GPS – ingen navigering, och de lägen som behöver den beter sig säkert (se [tabellen](#vad-varje-läge-behöver)).

---

## Standardfördelning på sändaren

FS-i6 + FS-iA6B, iBUS, 10 kanaler (`config/Channels.h`).

| Kanal | Reglage på sändaren | Standard |
|---|---|---|
| CH1–CH4 | spakar | roll, tippning, gas, sidroder (kan inte tilldelas om) |
| CH5 | **SwA** | **ARM** (ned = armerad, bara med gasen i botten; kan inte tilldelas om) |
| CH6 | SwB | klaffar (`Feature::FLAPS`) |
| CH7 | **SwC** (3 lägen) | upp **MANUAL** · mitten **STABILIZE** · ned **AUTO_TAKEOFF** |
| CH8 | SwD | **RTH** – hem, så länge den är påslagen |
| CH9 | VrA | stabiliseringens styrka (`Knob::STAB_GAIN`) |
| CH10 | VrB | marschfart (`Knob::CRUISE_SPEED`) |

När kortet startar skriver seriemonitorn ut den faktiska fördelningen – det som verkligen är flashat (firmwaren skriver på ryska; ”вверх / середина / вниз” betyder upp / mitten / ned):

```
SwC (CH7): MANUAL / STABILIZE / AUTO_TAKEOFF (вверх / середина / вниз)
SwB (CH6): FLAPS, пока включён
SwD (CH8): RTH, пока включён
VrA (CH9): крутилка STAB_GAIN
VrB (CH10): крутилка CRUISE_SPEED
```

> Kanalerna 7–10 är inte påslagna på FS-i6 från början. I sändarens meny: **Functions setup → Aux. channels**, tilldela SwC, SwD, VrA, VrB.

---

## Tilldela en funktion med en enda rad

Allt finns i en fil – `include/config/Controls.h`:

```cpp
constexpr Binding BINDINGS[] = {
    Bind::modes  (Channels::SWC, MODE_MANUAL, MODE_STABILIZE, MODE_AUTO_TAKEOFF),
    Bind::feature(Channels::SWB, Feature::FLAPS),
    Bind::mode   (Channels::SWD, MODE_RTH),
    Bind::knob   (Channels::VRA, Knob::STAB_GAIN),
    Bind::knob   (Channels::VRB, Knob::CRUISE_SPEED),
};
```

| Radens form | Vad den gör |
|---|---|
| `Bind::modes(kanal, upp, mitten, ned)` | en trelägesbrytare väljer läget |
| `Bind::modes(kanal, upp, ned)` | en tvålägesbrytare – två lägen |
| `Bind::mode(kanal, läge)` | ett läge **ovanpå** de andra så länge brytaren är på; slå av den så återkommer läget från lägesbrytaren |
| `Bind::feature(kanal, funktion)` | funktionen verkar så länge brytaren är på |
| `Bind::knob(kanal, ratt)` | en ratt: mitten = värdet från `Config.h`, ändlägena = minimum och maximum |

”På” betyder att kanalen är över 1750 µs (på FS-i6, brytaren ned, mot dig). Tills den första ramen från mottagaren kommer räknas alla kanaler som avslagna: ingenting fälls ut eller släpps vid start.

### Färdiga recept

```cpp
// Termikglidare: SwD – termikflygning, SwB – autotrimning, VrB – cirkelradie
Bind::modes  (Channels::SWC, MODE_MANUAL, MODE_STABILIZE, MODE_CRUISE),
Bind::mode   (Channels::SWD, MODE_SOARING),
Bind::feature(Channels::SWB, Feature::AUTO_TRIM),
Bind::knob   (Channels::VRA, Knob::STAB_GAIN),
Bind::knob   (Channels::VRB, Knob::LOITER_RADIUS),

// Elev: bara stabilisering, RESCUE på en "panikknapp", mjuka spakar
Bind::modes  (Channels::SWC, MODE_STABILIZE, MODE_ALT_HOLD, MODE_CRUISE),
Bind::mode   (Channels::SWD, MODE_RESCUE),
Bind::feature(Channels::SWB, Feature::GEOFENCE),
Bind::knob   (Channels::VRA, Knob::RATES),
Bind::knob   (Channels::VRB, Knob::MAX_BANK),

// Filmning och leverans: kamera med stabilisering, lastsläpp, cirkling över en punkt
Bind::modes  (Channels::SWC, MODE_STABILIZE, MODE_CRUISE, MODE_LOITER),
Bind::feature(Channels::SWB, Feature::PAYLOAD_DROP),
Bind::feature(Channels::SWD, Feature::CAMERA_STAB),
Bind::knob   (Channels::VRA, Knob::CAMERA_TILT),
Bind::knob   (Channels::VRB, Knob::LOITER_RADIUS),

// Handstart utan landningsställ: SwD – LAUNCH, klaffar steglöst på en ratt
Bind::modes  (Channels::SWC, MODE_MANUAL, MODE_STABILIZE, MODE_CRUISE),
Bind::mode   (Channels::SWD, MODE_LAUNCH),
Bind::feature(Channels::SWB, Feature::AIRBRAKE),
Bind::knob   (Channels::VRA, Knob::FLAPS),
Bind::knob   (Channels::VRB, Knob::CRUISE_SPEED),
```

### Kompilatorn fångar misstag

Tabellen kontrolleras vid bygget (`static_assert`), innan firmwaren hamnar i flygplanet:

- spakarna och SwA (ARM) kan inte bindas, och kanalnumret måste vara mindre än `Channels::COUNT`;
- en kanal har bara en bindning;
- det får finnas högst en lägesväljare (`Bind::modes`).

Om flera `Bind::mode`-brytare är på samtidigt vinner den översta raden i tabellen.

---

## Lägen

Läget byts när en brytare **slås om**. Ett läge som slagits på från panelen eller markstationen gäller tills piloten slår om en lägesbrytare igen. OLED-skärmen visar ett kort namn (inom parentes).

### MANUAL (MAN)
Ytor = spakar, som utan flygkontroller. Bara funktionerna (klaffar, broms, last) och autotrimningen verkar. **Det viktigaste säkerhetsläget**: ha det alltid på en brytare under fingret.

### STABILIZE (STAB) – ”spaken anger vinkeln”
Rollspaken anger krängningsvinkeln upp till `MAX_BANK_DEG` (45°, ratten `MAX_BANK` 15…60°), tippspaken anger vinkeln upp till `STAB_MAX_PITCH_DEG` (25°). Släpp – flygplanet rätar upp sig självt. Gasen är pilotens. PID-integratorn ackumulerar bara nära målet (±10°), så efter en skarp manöver ”skjuter” flygplanet inte förbi horisonten.
**Behöver:** IMU. Utan IMU – samma som MANUAL.

### ALT_HOLD (ALT) – ”håll höjden”
Som STABILIZE i roll, medan höjdrodret håller höjden med barometern. Rör tippspaken – du flyger själv; släpp – flygplanet håller den **nya** höjden. Gasen är pilotens (ge gas, annars räcker inte farten för att stiga).
**Behöver:** IMU + barometer.

### ACRO – ”spaken anger rotationshastigheten”
Fullt spakutslag – 180°/s. Släpp – flygplanet **håller den attityd det hade** (även upp och ned), och gyroskopet dämpar byar. För avancerad flygning.
**Behöver:** IMU. Utan IMU – ytor = spakar.

### CRUISE (CRZ) – ”håll kurs, höjd och fart”
Flygplanet flyger rakt på den aktuella höjden, med automatisk gas (ratten `CRUISE_SPEED`: 30…55…85 % gas, och med pitotrör – **lufthastighet** 10…14…22 m/s). Rollspaken svänger (släpp – den håller den nya kursen), tippspaken ändrar höjden. Med pitotrör verkar överstegringsskyddet. Kursen kommer från GPS (vid en markhastighet > 3 m/s, tillbaka till kompassen under 2 m/s), annars från kompassen, annars från gyroskopet. I simulering, med 4 m/s sidvind, håller markspåret sig inom ±5° och höjden inom ±3 m.
**Behöver:** IMU + barometer; GPS eller kompass för en kurs utan avdrift.

### LOITER (LOIT) – ”cirkla här”
Cirklar medurs över punkten där läget slogs på, radie 50 m (ratten `LOITER_RADIUS` 25…150 m), på den aktuella höjden, med automatisk gas. Styrningen är ett vektorfält: på långt avstånd ansluter flygplanet till cirkeln längs en tangent, och på cirkeln håller det en framkopplad krängning. Utan GPS – bara en cirkel med konstant krängning på stället.
**Behöver:** IMU + barometer + GPS.

### RTH – ”hem”
Kurs mot hempunkten (ARM-punkten), höjd `RTH_ALTITUDE_M` = 40 m (under den – stiger på vägen, över den – stannar kvar). Över hempunkten – cirklar med LOITER-radien tills piloten tar över. Ingen GPS eller ingen hempunkt – cirklar på stället. Samma läge kopplas in vid förlorad förbindelse och av geofencen.
**Behöver:** IMU + barometer + GPS med hempunkt.

### AUTO_TAKEOFF (TKOFF) – ”start på gas”
Efter ARM händer ingenting förrän piloten höjer gasen över mitten. Sedan programmet: 1 s acceleration till 100 % gas med vingarna plana, 2 s rotation med tippning 15°, sedan stigning med tippning 10° tills piloten byter läge. Spakarna läggs ovanpå programmet – du kan räta upp kursen under startrullningen.
**Behöver:** IMU.

### LAUNCH (LNCH) – ”handstart”
1. Armerat, gas över mitten – starten är **förberedd**, motorn står still.
2. Kastet: acceleration framåt > 1,5 g i mer än 40 ms.
3. Efter 0,3 s (handen är borta från propellern) – gas 100 %, stigning med tippning 15°, vingarna plana – i 6 s eller till 30 m.
4. Därefter – som CRUISE på den nådda höjden.

Varje spakrörelse (> 150 µs) före kastet avbryter det: flygplanet är i pilotens händer.
**Behöver:** IMU (accelerometer). I simulering: ett kast i 9 m/s från handhöjd – flygplanet rör aldrig marken och stiger mer än 15 m på 15 s.

### AUTO_LAND (LAND) – ”landning”
Motorn är av, glidflykt på kurs med tippning −4°; under 3 m enligt barometern – flare (+4°). Rollspaken justerar inflygningskursen. Koppla in det på en rak sträcka, mot vinden, på 20–40 m, med bana att ta av. I simulering sker sättningen med en vertikal hastighet under 1,5 m/s, vingarna plana, inte på nosen.
**Behöver:** IMU + barometer (nollställd på marken vid start).

### SOARING (SOAR) – ”termikflygning”
Motorn är av, glidflykt. En variometer (med pitotrör – totalenergi, utan falsk ”termik” av att dra spaken bakåt) över 0,5 m/s i mer än 1,5 s – termik: cirklar med 25° krängning. En genomsnittlig stigning över 8 s som sjunker under −0,2 m/s – ut ur termiken. Under 30 m – motorn tills 100 m; längre bort än 400 m från hempunkten – glider hem. I simulering hittar den en termik (en kärna på 3 m/s) och stiger mer än 50 m utan motor.
**Behöver:** IMU + barometer; GPS – för att återvända hem.

### RESCUE (RESQ) – ”rädda mig”
Vingarna plana, nosen +8°, gas 70 % – ur vilken spiral som helst. Tappat orienteringen? Slå om brytaren och andas ut. I simulering, från en spiral med 70° krängning och nosen på −40°, på 4 s – vingarna plana och stigning.
**Behöver:** IMU.

---

## Funktioner (brytare)

| Funktion | Vad den gör | Detaljer och siffror (`Config.h`) |
|---|---|---|
| `FLAPS` | båda skevrodren ned – flaperoner | `FLAPS_DEPLOYED_US` = 220 µs, mjukt på 1 s; roll verkar ovanpå |
| `AIRBRAKE` | båda skevrodren upp – en luftbroms, brantare glidbana | `AIRBRAKE_US` = 250; har företräde framför klaffarna |
| `AUTO_TRIM` | lär sig hålla flygplanet rakt utan spakarna: det stadiga roderkommandot i planflykt ”flyter över” i trimmet | 20 %/s, upp till ±120 µs; sparas i flash efter DISARM **på marken** |
| `TURN_COORDINATION` | sidroder in i svängen, nosen upp i krängningen | alltid på i navigeringslägena |
| `MOTOR_KILL` | motorn är av i alla lägen, även de automatiska | går före alla lägen och gasen |
| `BEEPER` | ”jag är här”-summern | utan brytare piper den av sig själv: på marken, förbindelsen bruten > 10 s |
| `PAYLOAD_DROP` | AUX1-servot är öppet så länge brytaren är på | 1000 µs stängt, 2000 öppet |
| `GEOFENCE` | längre bort än 500 m från hempunkten eller högre än 120 m – RTH | `GEOFENCE_ALWAYS_ON` – utan brytare |
| `HOME_RESET` | hempunkt = den aktuella punkten (i det ögonblick brytaren slås på) | bara med bra GPS |
| `CAMERA_STAB` | kameran på AUX2 håller sin vinkel mot horisonten | flygplanets tippning dras ifrån |

## Rattar

Mitten på en ratt = standardvärdet från `Config.h`; ändlägena är minimum och maximum. Om en ratt inte är bunden gäller standardvärdet.

| Ratt | Minimum … mitten … maximum | Var den verkar |
|---|---|---|
| `STAB_GAIN` | ×0,25 … ×1 … ×2 | alla lägen med stabilisering, och ACRO – ”mjukare/hårdare” |
| `MAX_BANK` | 15° … 45° … 60° | den största krängningen från spaken och från navigeringen |
| `CRUISE_SPEED` | gas 30 … 55 … 85 % (med pitotrör: 10 … 14 … 22 m/s) | CRUISE, LOITER, RTH, motorn i SOARING |
| `FLAPS` | 0 … 50 … 100 % klaffar | steglösa klaffar i stället för en brytare |
| `CAMERA_TILT` | −90° … 0° … +30° | kameravinkeln (AUX2) |
| `RATES` | 30 … 65 … 100 % av spakutslaget | alla lägen: spakkänslighet |
| `LOITER_RADIUS` | 25 … 50 … 150 m | LOITER och cirklar över hempunkten |

> Ett användbart knep: ratten `STAB_GAIN` på VrA är ”levande” justering av koefficienterna under flygning. Om det svänger – vrid ned; om det är trögt – vrid upp; för sedan över multiplikatorn till `Config.h`.

---

## Förlorad förbindelse, geofence, hem

**Hempunkten** registreras vid ARM om GPS:en är bra (3D-fix, ≥ 6 satelliter, noggrannhet ≤ 5 m). Om GPS:en inte har låst före ARM registreras hempunkten så snart den gör det. För att ändra den på fältet – funktionen `HOME_RESET`.

**Förlorad förbindelse** (inga iBUS-ramar på > 0,5 s, eller mottagaren skickade en gas under 950 µs – det är den failsafe som ställts in i sändaren; se `docs/PILOT_GUIDE.md`):

| Situation | Vad planet gör |
|---|---|
| på marken (inte armerat) | motor 0, ytor till neutralläge; efter 10 s – summern |
| i luften, GPS och hempunkt finns | **RTH** med motor, över hempunkten – cirklar på 40 m |
| i luften, ingen GPS | **glidflykt**: motorn av, vingarna plana, nosen −3° |
| förbindelsen är tillbaka | direkt läget från pilotens brytare |

En hemflygning som redan har börjat övergår inte till glidflykt på grund av en kort GPS-förlust. `FAILSAFE_RTH = false` – bara glidflykt.

**Geofence** (`GEOFENCE` eller `GEOFENCE_ALWAYS_ON`): flyger planet längre bort än `FENCE_RADIUS_M` (500 m) eller högre än `FENCE_ALTITUDE_M` (120 m) – RTH. För att ta tillbaka kontrollen, slå om en lägesbrytare till vilket annat läge som helst (ett läge slås på genom att läget ändras). Den löser ut igen när flygplanet har kommit tillbaka innanför med 10 % marginal.

---

## Ett hemmabyggt pitotrör

Lufthastighet utan en köpt differenstrycksensor: **två barometrar**.

```
     mötande luftström ─►  ┌────────────── rör (PVC/mässing, Ø4–6 mm) ──┐
                            │  BMP581 (I2C 0x47) – totaltryck         │  lufttätt
                            └─────────────────────────────────────────┘
   flygkropp: huvudbarometer (BMP581 0x46 / SPL06 / BMP388) – statiskt tryck

   hastighet  V = √(2·(P_rör − P_statiskt − noll) / ρ),   ρ – från statiskt tryck och temperatur
```

**Montering.** BMP581 (en modul med adress 0x47: stiftet SDO till VCC) limmas in i ett rör som bara är öppet framtill – kortet sitter i ett lufttätt hålrum, med trådarna utdragna genom tätningsmassa. Röret pekar framåt, utanför propellerströmmen (på vingen eller ovanför nosen). Den andra barometern sitter inne i flygkroppen, skyddad från den direkta luftströmmen (skumplast).

**Påslagning i firmwaren** – `sensors/SensorSelection.h`: `SENSOR_KIT_LSM6DSV_PITOT` eller `SENSOR_KIT_ICM45686_PITOT` (färdiga satser), eller `SENSOR_AIRSPEED = SENSOR_AIRSPEED_PITOT_BMP581` i din egen sats.

**Nollpunkt.** Två barometrar skiljer sig alltid lite åt: den absoluta noggrannheten hos var och en är tiotals pascal, och det är hela tryckskillnaden vid låg fart (10 m/s ≈ 60 Pa). Under den första sekunden efter start medelvärdesbildar firmwaren skillnaden och tar den som noll. **Flygplanet står stilla vid start, och röret är täckt med ett finger eller ett lock, eller vänt mot vinden.** På OLED-skärmen, i panelen och i telemetrin visas hastigheten efter nollställningen.

**Kalibrering av `PITOT_SCALE`.** Trycket inne i flygkroppen är inte strikt statiskt. Flyg i stilla luft en rak sträcka fram och tillbaka i CRUISE och jämför den genomsnittliga markhastigheten från GPS med rörets hastighet: `PITOT_SCALE = V_GPS / V_rör`.

**Skydd.** En starkt negativ tryckskillnad i mer än 2 s (förväxlade slangar, vatten) eller rörmätningar äldre än 0,2 s – ingen hastighet matas ut, och autopiloten faller tillbaka på gasen från ratten och flyger kursen utan lufthastighet. Verifierat i en simulering i sluten slinga med brus på båda barometrarna: hastighetsfelet under flygning är < 0,5 m/s.

Vad röret ger dig: CRUISE håller **lufthastigheten** i stället för gasen; överstegringsskydd; en totalenergivariometer för SOARING; en ärlig hastighet i telemetrin.

---

## Markstation: Wi-Fi-panel och MAVLink

**ESP32 – Wi-Fi-panel.** Åtkomstpunkten `OpenPlane-Debug`, lösenord `12345678`, adressen står i seriemonitorn. Kanaler, utgångar, alla sensorer, läget, navigering, de påslagna funktionerna; du kan ändra läget och PID. Detaljer – `docs/PILOT_GUIDE.md`.

**STM32H743 – MAVLink via radiomodem** (UART4: PD0 RX, PD1 TX, 57600 baud – SiK-standard). SiK 433/868/915 MHz, ELRS i MAVLink-läge och en ESP-01 som Wi-Fi-brygga fungerar alla. **QGroundControl** och **Mission Planner** ser planet som ett ArduPilot-flygplan:

- horisonten, en karta med hempunkten, hastighet (från pitotröret, om det finns), höjd, variometer, gas;
- lägen under ArduPlane-namnen: STABILIZE → FBWA, ALT_HOLD → FBWB, CRUISE → CRUISE, LOITER → LOITER, RTH → RTL, AUTO_TAKEOFF/LAUNCH → TAKEOFF, SOARING → THERMAL, RESCUE → STABILIZE, AUTO_LAND → AUTO; failsafe visas som RTL eller CIRCLE;
- ett meddelandeflöde: ARM/DISARM, lägesbyten (under vårt eget namn), förlorad förbindelse, geofence;
- **byte av läge från marken** – med lägesknappen i GCS:en (utom AUTO: OpenPlane har inga uppdrag);
- **parametrar** `RLL_KP … PTCH_KD` – PID för roll och tippning, läses och ändras från GCS:ens parameterfönster mitt under flygningen (de sparas inte över en omstart – för över bra värden till `Config.h`).

ARM/DISARM från marken **avvisas** – bara med sändarens brytare. För att kontrollera strömmen utan hårdvara: `OPENPLANE_MAVLINK_DUMP=/tmp/tlm.bin pio test -e native -f native/test_mavlink && python3 tools/check_mavlink.py /tmp/tlm.bin` (kräver `pip install pymavlink`).

---

## Inställning av ett nytt flygplan, steg för steg

1. **MANUAL på marken:** rodrens riktningar (`*_REVERSED` i `Config.h`), klaffar ned, AUX. Kontrollera utgångarna med `p` i konsolen (propellern av!).
2. **Sensorer på marken:** `b` – bussavsökning, `s` – status; `o` – kalibrering av IMU-monteringen (3 positioner, en gång), `m` – kompass.
3. **STABILIZE på marken:** luta flygplanet åt höger – det högra skevrodret ska gå **ned** (för att räta upp det). Nosen upp – höjdrodret ned. Om inte – reverseringarna eller IMU-monteringen är förväxlade.
4. **Den första flygningen i MANUAL**, stig till minst 50 m → STABILIZE. Om det svänger – sänk `STAB_GAIN`; om det är trögt – höj den.
5. **AUTO_TRIM** i planflykt i 20–30 s, landa, DISARM – trimmet sparas.
6. **ALT_HOLD**, sedan **CRUISE** – kontrollera höjd och kurs; med pitotrör – kalibrera `PITOT_SCALE`.
7. **LOITER** och **RTH** – på höjd, inom synhåll, fingret på MANUAL.
8. Först därefter – **failsafe-testet** (stäng av sändaren på höjd, flygplanet ska styra hemåt) och automatisk start/landning.

## Autopilotens kontroll före flygning

- [ ] Fördelningen som skrivs ut vid start är den du förväntar dig.
- [ ] Konsol/OLED: IMU ok, IMU-kontrollen före flygning godkänd (flygplanet stod stilla vid start).
- [ ] Barometern är nollställd på marken (höjd ~0 på OLED-skärmen).
- [ ] Med pitotrör: hastighet ~0 på marken, blås i röret – den stiger.
- [ ] GPS: 3D-fix, ≥ 6 satelliter **före ARM** – annars blir det ingen hempunkt och ingen RTH.
- [ ] STABILIZE på marken: skevrodren och höjdrodret rätar upp flygplanet i stället för att välta det.
- [ ] Failsafe är inställt i sändaren (gas under 950 vid förlorad förbindelse) och verifierat genom att stänga av sändaren **på marken** utan propeller.
- [ ] MANUAL – under fingret.

---

## Vad varje läge behöver

| Läge | IMU | Barometer | GPS | Kompass | Pitot | Gas | Utan den nödvändiga sensorn |
|---|:-:|:-:|:-:|:-:|:-:|---|---|
| MANUAL | | | | | | pilot | – |
| STABILIZE | ● | | | | | pilot | ytor = spakar |
| ALT_HOLD | ● | ● | | | | pilot | piloten håller höjden |
| ACRO | ● | | | | | pilot | ytor = spakar |
| CRUISE | ● | ● | ○ | ○ | ○ | auto | kurs från gyroskopet (driver), höjden hos piloten |
| LOITER | ● | ● | ● | | ○ | auto | en cirkel med krängning på stället |
| RTH | ● | ● | ● | | ○ | auto | cirklar på stället |
| AUTO_TAKEOFF | ● | | | | | program | ytor = spakar + pilotens gas |
| LAUNCH | ● | ○ | | | | program | ytor till neutralläge |
| AUTO_LAND | ● | ● | | ○ | | 0 | ingen flare |
| SOARING | ● | ● | ○ | | ○ | 0 / motor | ingen termik – glidflykt |
| RESCUE | ● | | | | | 70 % | ytor till neutralläge |

● – krävs, ○ – förbättrar. Kontroller i koden: `Autopilot.h` (`imuReady`, `baroReady`, `nav.gpsGood`); tester – `test/native/test_autopilot_modes` (hur lägena reagerar på varje sensor) och `test/native/test_sim` (flygningar i sluten slinga).

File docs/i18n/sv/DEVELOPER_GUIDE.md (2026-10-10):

# DEVELOPER_GUIDE.md – utvecklarhandbok för OpenPlaneProject

> 🌐 Den här sidan är en översättning av [det ryska originalet](../../DEVELOPER_GUIDE.md). Om översättningen och originalet skiljer sig åt gäller originalet. Firmwaren skriver ut sina konsolmeddelanden på ryska, så de citeras oförändrade. Översättningen är gjord av AI och har inte granskats av personer med svenska som modersmål. Rapportera fel till [Damir Lebedev](https://github.com/damir-lebedev) eller i [ärendehanteraren](https://github.com/damir-lebedev/OpenPlaneProject/issues).

En teknisk karta över firmwaren: vilken fil som ansvarar för vad, hur data flödar från mottagaren och sensorerna till servona, vilka teckenkonventioner som håller ihop hela kedjan, hur webb-API:t är organiserat och hur man bygger ut projektet. Den är avsedd för en utvecklare som skriver C++ och snabbt vill hitta rätt i det här repositoryt (grenen `main`), inte för att lära sig grunderna i språket eller i PlatformIO.

En översikt över projektet och prototypens status finns i [`../README.md`](README.md); vad som kopplas vart och hur man flyger finns i [`PILOT_GUIDE.md`](PILOT_GUIDE.md); planerna finns i [`ROADMAP.md`](ROADMAP.md). Här finns bara kod. Hela arkitekturen (lager, uppgifter, tillståndsmaskiner) finns i [`ARCHITECTURE.md`](ARCHITECTURE.md), en referens för varje klass i [`reference/`](reference/README.md) och testerna i [`TESTING.md`](TESTING.md).

> Projektet är under aktiv utveckling. ESP32-S3-bänken är monterad och verifierad med alla sensorer, men **autopiloten har ännu inte provats under flygning** – det noteras överallt där det gäller en specifik modul. Om du tvivlar på vad koden gör, läs källkoden igen, inte dokumentet.

---

## Innehåll

1. [Lagrens arkitektur](#lagrens-arkitektur)
2. [FreeRTOS-uppgifter och styrslingan](#freertos-uppgifter-och-styrslingan)
3. [Filreferens](#filreferens)
4. [Teckenkonvention: från IMU:n till servot](#teckenkonvention-från-imun-till-servot)
5. [RC-kanalkarta, ARM och failsafe](#rc-kanalkarta-arm-och-failsafe)
6. [Sensordata](#sensordata)
7. [Genomgång av FlightController::update()](#genomgång-av-flightcontrollerupdate)
8. [Webbpanelens HTTP-API](#webbpanelens-http-api)
9. [Konsol och diagnostik](#konsol-och-diagnostik)
10. [Val av kort och stiftbeläggning](#val-av-kort-och-stiftbeläggning)
11. [Hur man lägger till en ny sensor](#hur-man-lägger-till-en-ny-sensor)
12. [Hur man lägger till ett nytt autopilotläge](#hur-man-lägger-till-ett-nytt-autopilotläge)
13. [Återkoppling (förarbete, inte ansluten)](#återkoppling-förarbete-inte-ansluten)
14. [Hur man lägger till ett nytt kort](#hur-man-lägger-till-ett-nytt-kort)
15. [Kommandon för bygge, uppladdning och monitor](#kommandon-för-bygge-uppladdning-och-monitor)
16. [Kända begränsningar](#kända-begränsningar)
17. [Hur man gör ändringar](#hur-man-gör-ändringar)

---

## Lagrens arkitektur

Nästan alla klasser finns i headerfiler utlagda i mapparna `include/<lager>/`. Varje headerfil inkluderar själv det den använder (`#include "config/Config.h"`, `"hal/II2CBus.h"`, ... – sökvägar från `include/`). `src/main.cpp` är den enda monteringspunkten (composition root): den skapar alla objekt, länkar dem och kör `setup()`/`loop()`. Beroendena är enkelriktade – ett lägre lager vet ingenting om ett övre.

```
include/
├── config/      Config.h (stift, alla inställningar), Channels.h (kanalnamn),
│                Controls.h (vad varje brytare gör – en rad per kanal)
├── hal/         IBoard, II2CBus, ISpiBus, IUartPort, IServoOutput,
│   │            RegisterDevice (en registerenhet ovanpå I2C/SPI), Rtos
│   ├── esp32/   Esp32Board + omslag kring Wire/SPI/HardwareSerial/LEDC
│   └── stm32/   Stm32Board + Wire/SPI/Uart/HardwareTimer, Stm32FlashStorage,
│                compat/Preferences.h (inställningar i flash i stället för NVS)
├── storage/     KeyValueStore, KvPreferences – lagring av inställningar utan NVS
├── rc/          RcChannelState, RcInput, IBusReceiver
├── control/     ControlCommand, ControlMixer, FlapsController,
│                ThrottleManager, ArmingManager, FlightOutputState,
│                FlightOutputs, Beeper, FlightController
├── autopilot/   AutopilotTypes, ControlBinding, PilotSwitches, Autopilot,
│   │            Navigation, AltitudeSpeedController, LaunchController,
│   │            SoaringController, AutoTrim, PidController
│   └── feedback/  förarbete till återkopplingsslingan – INTE ansluten (se avsnittet nedan)
├── sensors/     SensorInterface, SensorSelection, SensorMounting
│   ├── imu/     ImuSensorBase, AttitudeEstimator, MPU6050, ICM42688, LSM6DSV, ICM45686
│   ├── baro/    BarometerBase, BMP388, BME280, SPL06, BMP581
│   ├── mag/     MagnetometerBase, QMC5883P, QMC5883L, QMC6309
│   ├── gps/     UbloxM10_Gps
│   └── airspeed/ AirspeedSensor, PitotDualBaroAirspeed (ett rör av två barometrar)
└── telemetry/   DebugLogger, DebugConsole, WebDebugServer, WebDashboardPage,
                 OledDisplay, LoopStats, MavlinkCodec, MavlinkTelemetry
src/main.cpp        — ESP32-firmware (S3, C3, 38-pin)
src/stm32/main.cpp  — STM32H743-firmware (FreeRTOS-uppgifter, MAVLink)
```

```
┌───────────────────────────────────────────────────────────────────────┐
│ APPLIKATION  src/main.cpp / src/stm32/main.cpp – montering av objekt  │
└──────────────────────────────┬────────────────────────────────────────┘
                               ▼
┌───────────────────────────────────────────────────────────────────────┐
│ KOORDINERING  control/FlightController – operationsordning per cykel   │
│ TELEMETRI     DebugLogger, DebugConsole, Web (ESP32) / MAVLink, OLED   │
└───────┬───────────────────────┬───────────────────────┬───────────────┘
        ▼                       ▼                       ▼
┌────────────────────┐  ┌──────────────────────┐  ┌──────────────────────┐
│ STYRNING            │  │ AUTOPILOT             │  │ RC                    │
│ ControlMixer        │  │ Autopilot: 12 lägen   │  │ IBusReceiver          │
│  └ FlapsController  │  │  └ navigering, PID    │  │ RcChannelState        │
│ ThrottleManager     │  │ PilotSwitches         │  │ RcInput               │
│ ArmingManager       │  └──────────┬────────────┘  └───────────────────────┘
│ FlightOutputs       │             │ ImuSensor* / BarometerSensor* / ...
└─────────┬───────────┘             ▼
          │           ┌─────────────────────────────────────────────────┐
          │           │ SENSORER                                         │
          │           │ ImuSensorBase ── MPU6050, ICM42688, LSM6DSV,     │
          │           │   └ AttitudeEstimator     ICM45686               │
          │           │ BarometerBase ── BMP388, BME280, SPL06, BMP581   │
          │           │ MagnetometerBase ── QMC5883P / L, QMC6309        │
          │           │ UbloxM10_Gps, PitotDualBaroAirspeed              │
          │           └──────────────────────┬──────────────────────────┘
          ▼                                  ▼ IRegisterDevice / IUartPort
┌───────────────────────────────────────────────────────────────────────┐
│ HAL  IBoard / II2CBus / ISpiBus / IUartPort / IServoOutput             │
│      RegisterDevice: I2cRegisterDevice, SpiRegisterDevice              │
│      esp32/Esp32Board — Wire, Wire1, SPI, HardwareSerial, LEDC         │
│      stm32/Stm32Board — Wire, I2C1, SPI, Uart, HardwareTimer, flash    │
└───────────────────────────────────────────────────────────────────────┘
```

Reglerna som håller arkitekturen ren:

- **HAL** är det enda lagret som får känna till en specifik mikrokontroller (`Wire`, `SPI`, `HardwareSerial`, `ledc*`). Allt ovanför arbetar bara med gränssnitt. Att flytta till en annan mikrokontroller innebär en ny `hal/<mcu>/<Mcu>Board.h`; resten av koden ändras inte (ett exempel är `hal/stm32/` för STM32H743).
- **Sensordrivrutiner känner inte till bussen.** De får en `IRegisterDevice&` – en I2C-enhet med en adress eller en SPI-enhet med en CS skapas i `SensorSelection.h`. Samma `BMP388_Sensor` fungerar både över I2C och SPI.
- **Det som är gemensamt finns i basklasserna.** Kalibrering, axelrotation, tecken, orienteringsfiltret, höjd och vertikal hastighet, lagring av kompasskalibrering, räkning av bussfel – i `ImuSensorBase`/`BarometerBase`/`MagnetometerBase`. En kretsdrivrutin innehåller bara registren och formlerna från databladet.
- **RC och utgångar** vet ingenting om flygplanet: iBUS-byte → kanaler, PWM-värden → utgångar.
- **Styrning och Autopilot** är logik över data, utan UART, PWM eller Wi-Fi. Tid, där den behövs (klaffar), skickas som parameter.
- **Koordinering** (`FlightController`) är den enda klassen som ser flera lägre lager samtidigt och bestämmer operationsordningen.
- **Applikation** (`main.cpp`) är det enda stället där `Esp32Board`, enheterna och sensorerna skapas och där allt kopplas ihop för hand, utan ett DI-ramverk.

---

## FreeRTOS-uppgifter och styrslingan

| Var | Vad | Period |
|---|---|---|
| Kärna 1, `loop()` (Arduinos loopTask) | `applyPendingCommands()` → `FlightController::update()` → `DebugLogger::update()` → `DebugConsole::update()` | `Config::LOOP_PERIOD_MS` = 2 ms (500 Hz), `vTaskDelayUntil` |
| Kärna 0, uppgiften `web` | `WebServer::handleClient()` | var 2:a ms |
| Kärna 0, uppgiften `oled` | ritning av SSD1306 över den andra I2C-bussen | 200 ms |
| Kärna 0 | ESP-IDF:s Wi-Fi-stack | – |

- Slingans period hålls av `vTaskDelayUntil`, inte av `delay(2)` efter arbetet –
  frekvensen beror inte på hur länge cykeln varade. Efter ett långt block
  (en kalibrering från konsolen) börjar tidtagningen om, och de missade cyklerna
  tas inte igen i en skur.
- På bänken (ESP32-S3, alla sensorer): 500 Hz, i genomsnitt cirka ~0,7 ms arbete per
  cykel, den sämsta cykeln ~1,4 ms. Det skrivs ut var 10:e s som en `SYS:`-rad.
- Tidsgränsen för en I2C-transaktion är 5 ms (standard i Wire är 50 ms): en transaktion
  som hängt sig på grund av störningar stoppar inte slingan länge.
- **Dataseparation mellan uppgifter.** Webben och OLED-skärmen *läser* bara
  tillståndet (`FlightController`/`Autopilot`/`LoopStats`) – det är separata
  16/32-bitarsfält, så i värsta fall syns värdena från intilliggande cykler.
  Panelens *kommandon* (`setmode`/`setpid`) tillämpas inte direkt från
  webbuppgiften: de läggs i en ”brevlåda” under `portMUX` och hämtas av
  flygslingan i `WebDebugServer::applyPendingCommands()`.
- `Serial` (UART0 → CH343-bryggan → ”COM”-kontakten) med en sändbuffert på 4 KB:
  en felsökningsram (~600 tecken) blockerar inte slingan medan den skickas.

---

## Filreferens

### `config/`

| Fil | Ansvarar för |
|---|---|
| `Config.h` | Alla stift (ett block per kort: `BOARD_ESP32_S3/C3/CLASSIC`, `BOARD_STM32H743`) och inställningarna: iBUS och förlorad förbindelse; roderytornas utslag; klaffar; servoreversering; montering av IMU och kompass; ARM; failsafe (RTH eller glidflykt); pitotröret (`PITOT_*`); alla siffror för autopilotens lägen och funktioner; slingan; Wi-Fi; MAVLink; felsökning |
| `Channels.h` | Kanalnamn: `AILERON`, `ELEVATOR`, `THROTTLE`, `RUDDER`, `ARM`, `SWB`, `SWC`, `SWD`, `VRA`, `VRB` |
| `Controls.h` | Tabellen `BINDINGS`: vad varje brytare och ratt gör, en rad per kanal, kontroller med `static_assert` |

### `hal/`

| Fil | Ansvarar för |
|---|---|
| `IBoard.h` | Ingångspunkten till hårdvaran: `i2c()`, `displayI2c()` (en andra buss för skärmen, kan vara `nullptr`), `spi()`, `rcUart()`, `gpsUart()`, `telemetryUart()` (MAVLink, kan vara `nullptr`), `servo(ServoChannel::*)` (7 utgångar med AUX1/AUX2), `setBuzzer()` |
| `Rtos.h` | FreeRTOS-uppgifter på samma sätt på ESP32 (kärna 0) och STM32 (prioriteter), ledig heap |
| `II2CBus.h` | I2C-bussen: primitiver i stil med `Wire` + hjälparna `writeRegister()`, `readRegisters()` (kontrollerar att exakt `count` byte kom), `readRegister()`, `probe()` |
| `ISpiBus.h`, `IUartPort.h`, `IServoOutput.h` | SPI, UART, en PWM-utgång (`measurePulseUs()` – diagnostik av den verkliga pulsen) |
| `RegisterDevice.h` | `IRegisterDevice` – ”en uppsättning 8-bitarsregister”; `I2cRegisterDevice` (adress), `SpiRegisterDevice` (CS, frekvens, dummybyte före data) |
| `esp32/Esp32Board.h` | Implementeringen av `IBoard`: `Wire` (sensorer), `Wire1` (skärmen, om kretsen har två I2C-styrenheter), `SPI`, två `HardwareSerial`, 5 LEDC-kanaler |
| `esp32/Esp32I2CBus.h` | `II2CBus` ovanpå valfri `TwoWire`, tidsgräns 5 ms |
| `esp32/Esp32ServoOutput.h` | PWM via LEDC: 50 Hz, 14 bitar; stift −1 – utgången är inte dragen. Biblioteket ESP32Servo används inte – se [begränsningar](#kända-begränsningar) |
| `esp32/Esp32SpiBus.h`, `esp32/Esp32UartPort.h` | Tunna omslag kring `SPI` och `HardwareSerial` |
| `stm32/*` | STM32H743: `Stm32Board` (+ radiomodemets UART4), bussar, PWM-timrar, `Stm32FlashStorage` (inställningar i en flashsektor, skrivna av en bakgrundsuppgift), `compat/Preferences.h` |

### `storage/`

| Fil | Ansvarar för |
|---|---|
| `KeyValueStore.h` | En avbild ”namnrymd/nyckel → byte” med CRC32 i RAM ovanpå valfritt medium (`IFlashStorage`); ett identiskt värde skrivs inte om |
| `KvPreferences.h` | ESP32:s `Preferences`-API ovanpå `KeyValueStore` |

### `rc/`

| Fil | Ansvarar för |
|---|---|
| `RcChannelState.h` | En ögonblicksbild av de 10 kanalerna |
| `RcInput.h` | `clamp()`, `centered(us, max, reverse)` |
| `IBusReceiver.h` | iBUS → kanaler: en ram på 32 byte, CRC, kanalvärdet är de låga 12 bitarna (`& 0x0FFF`); `isSignalLost()` = inga ramar (eller inga ännu) ∥ failsafe-värdet för gas; ramräknare |

### `control/`

| Fil | Ansvarar för |
|---|---|
| `ControlCommand.h` | Roderkommandot i fysiska tecken – det gemensamma språket för spakarna, autopiloten och mixern |
| `ControlMixer.h` | `fromSticks(rc)` → `ControlCommand`; `updateFlaps(target, now)`; `mix(command)` → PWM med servoreversering; flaperoner: skevrodren `flaps ± roll` (minus – luftbroms) |
| `FlapsController.h` | Mjuk utfällning/infällning av klaffarna, med tiden som parameter |
| `ThrottleManager.h` | Gas från spaken; vid förlorad förbindelse – `FAILSAFE_THROTTLE` |
| `ArmingManager.h` | ARM med brytaren SwA (en övergång OFF→ON med gasen i botten + lägets sensorkontroller), omedelbar DISARM |
| `FlightOutputState.h` | Önskad PWM: `aileronLeft`, `aileronRight`, `elevator`, `rudder`, `throttle`, `aux1` (last), `aux2` (kamera) |
| `Beeper.h` | Summern: via funktionen `BEEPER` eller ”modellen borttappad” på marken |
| `FlightOutputs.h` | Utgångstabellen (`outputInfo()`: nyckel, namn, stift, om den är obligatorisk, tillståndsfältet) och allt ovanpå den i en slinga: `begin()`, `write()`, `setFailsafe()`, status, `printPulseSelfTest()` |
| `FlightController.h` | Operationsordningen per cykel, förlorad förbindelse (`applyLinkLoss()`), getters för telemetri |

### `autopilot/`

| Fil | Ansvarar för |
|---|---|
| `AutopilotTypes.h` | `AutopilotMode` (12 lägen), `Feature`, `Knob`, `PilotInputs`, namn |
| `ControlBinding.h` | `Binding`, fabrikerna `Bind::modes/mode/feature/knob`, kontrollerna `BindingCheck` |
| `PilotSwitches.h` | Bindningstabellen → läget, funktionerna och rattarna i varje cykel; fördelningen vid start |
| `Autopilot.h` | 12 lägen, failsafe RTH/glidflykt, geofence, hempunkt, koordinerade svängar, autotrimning; `update(armed, linkLost, throttle, sticks)` → `getCommand()`, `applyThrottle()` |
| `Navigation.h` | `Geo` (avstånd, bäring, förskjutning), `Guidance` (roll för en kurs, cirkelns vektorfält) |
| `AltitudeSpeedController.h` | Tippning för höjd, gas för lufthastighet (TECS-lite) |
| `LaunchController.h`, `SoaringController.h` | Tillståndsmaskinerna för handstart och termikflygning |
| `AutoTrim.h` | Autotrimning, lagrad i NVS/flash |
| `PidController.h` | PID: D från sensorns hastighet (gyroskop, variometer), anti-windup, integratorn fryst utan ARM |
| `feedback/*` | **Förarbete, inte anslutet:** adaptiv återkoppling, start och landning – se [Återkoppling](#återkoppling-förarbete-inte-ansluten) |

### `sensors/`

| Fil | Ansvarar för |
|---|---|
| `SensorInterface.h` | Gränssnitten `Sensor`/`ImuSensor`/`BarometerSensor`/`MagnetometerSensor`/`GpsSensor` och datastrukturerna |
| `SensorSelection.h` | Vilken krets som kompileras in (`#define SENSOR_*`, kan åsidosättas med en byggflagga) och på vilken buss (`SELECTED_*_DEVICE(board)`) |
| `SensorMounting.h` | Rotation av kretsens axlar till flygplanets axlar (0/90/180/270° medurs) – för kompassen och för en IMU utan monteringskalibrering |
| `imu/ImuOrientation.h` | IMU-montering som en matris ”kretsens axlar → flygplanets axlar”: från `IMU_ROTATION_CW_DEG` eller från tre positioner (plant, nosen upp, höger vinge ned) med rimlighetskontroll; lagras i NVS |
| `imu/ImuSensorBase.h` | Gemensam IMU-kod: gyrokalibrering + kontroll före flygning (stillhet, 1g, ”upp” stämmer med monteringen), monteringskalibrering (`calibrateOrientation()`), skala, rotation, flygtekniska tecken, bussfel |
| `imu/AttitudeEstimator.h` | Komplementärfilter för roll/tippning, girintegral |
| `imu/MPU6050_Sensor.h` | MPU6050/MPU6500 (kretsen identifieras med WHO_AM_I): ±2000°/s, ±16g, DLPF ~41 Hz, 1 kHz. **På bänken** |
| `imu/ICM42688_Sensor.h` | ICM-42688-P: ±2000°/s, ±16g, 1 kHz, UI-filter 50 Hz. Inte provad på hårdvara |
| `imu/LSM6DSV_Sensor.h` | LSM6DSV/16X/32X: ±2000°/s, ±16g, 960 Hz, LPF1/LPF2; I2C 0x6A/0x6B eller SPI. Inte provad på hårdvara |
| `imu/ICM45686_Sensor.h` | ICM-45686: ±2000°/s, ±16g, 1,6 kHz, lågpassfilter via de indirekta IPREG-registren; I2C 0x68/0x69 eller SPI. Inte provad på hårdvara |
| `baro/BarometerBase.h` | Gemensam barometerkod: avläsning bara av nya mätningar, höjd, vertikal hastighet via ett lågpassfilter, baskalibrering, fel |
| `baro/BMP388_Sensor.h` | BMP388 över I2C eller SPI (med SPI:s dummybyte), Bosch-kompensering, avläsning på flaggan data-klar. **På bänken (I2C)** |
| `baro/BME280_Sensor.h` | BME280/BMP280, Bosch-kompensering §8.1. Inte provad på hårdvara |
| `baro/SPL06_Sensor.h` | SPL06-001: koefficienter och formler från databladet, 32 Hz ×16; I2C 0x76/0x77 eller SPI. Inte provad på hårdvara |
| `baro/BMP581_Sensor.h` | BMP581: sekvensen från BMP5_SensorAPI, 16×/2×, IIR; I2C 0x46/0x47 eller SPI; fungerar både som huvudbarometer (standardsatsen på bänken) och som pitotrör. Inte provad på hårdvara |
| `mag/MagnetometerBase.h` | Gemensam kompasskod: avläsning med 50 Hz, hard-iron-kalibrering i NVS, axelrotation, kurs, fel |
| `mag/QMC5883P_Sensor.h` | QMC5883P, 0x2C. **På bänken** |
| `mag/QMC5883L_Sensor.h` | QMC5883L, 0x0D |
| `mag/QMC6309_Sensor.h` | QMC6309, 0x7C: ±8 G, 200 Hz. Inte provad på hårdvara |
| `gps/UbloxM10_Gps.h` | u-blox M10: inställning med CFG-VALSET (115200 baud, 10 Hz, NAV-PVT, ingen NMEA), tolkning av NAV-PVT. Inte ansluten på bänken |
| `airspeed/AirspeedSensor.h` | Gränssnittet för lufthastighetssensorn: differenstryck, IAS, TAS, densitet |
| `airspeed/PitotDualBaroAirspeed.h` | Det hemmabyggda pitotröret: en BMP581 i röret + en barometer i flygkroppen; nollpunkt på marken, lågpassfilter, densitet från statiskt tryck, felupptäckt |

### `telemetry/` och applikationen

| Fil | Ansvarar för |
|---|---|
| `DebugLogger.h` | Logg per kanal (`LogSettings.h`): varje kanal har sin egen rad, sin egen debounce-tolerans och sitt eget läge; tyst medan menyn är öppen |
| `DebugConsole.h` | En textmeny i portmonitorn (`h`) och snabbtangenter (`l`/mellanslag/`s`/`i`/`o`/`m`/`p`/`b`); sparar logginställningarna i NVS när du lämnar menyn och bara utan ARM |
| `LogSettings.h` | Loggkanalerna (STAT, RC, OUT, ATT, AP, ALT, MAG, GPS, IMU, NAV, SYS) och deras lägen: av / vid ändring / kontinuerligt; lagras i NVS |
| `WebDebugServer.h` | Åtkomstpunkten, rutterna, JSON för `/api/status`, kommandobrevlådan; körs i en egen uppgift på kärna 0 |
| `WebDashboardPage.h` | Panelens HTML/JS som en enda literal; webbläsaren bygger raderna för kanaler/utgångar/sensorer från JSON |
| `OledDisplay.h` | SSD1306 via U8g2 ovanpå `II2CBus`, en egen uppgift (`Rtos`) |
| `MavlinkCodec.h`, `MavlinkTelemetry.h` | MAVLink 2 för QGroundControl / Mission Planner: ramar, strömmar, PID-parametrar, lägesbyte från marken |
| `LoopStats.h` | Frekvens, genomsnittlig och sämsta cykeltid per sekund (OLED) och den sämsta sedan senaste avläsningen (`takePeakUs()`, SYS-raden) |
| `src/main.cpp` | ESP32: skapande av objekten, `setup()`, `loop()` med `vTaskDelayUntil` |
| `src/stm32/main.cpp` | STM32H743: samma objekt, MAVLink, den svarta lådan på SD-kort, uppgifterna `flight`/`storage`/`oled`/`bbox` |
| `src/stm32/sd_msp.cpp`, `src/stm32/bootloader.cpp` | STM32H743: SDMMC1-stift och klockor för `HAL_SD_Init`; konsoltangenten `D` – omstart i USB DFU-bootloadern |

---

## Teckenkonvention: från IMU:n till servot

Ett teckensystem för hela kedjan – så att spaken och autopiloten garanterat
rör roderytorna åt samma håll, och riktningen för varje servo anges på
exakt ett ställe.

**1. Sensorns axlar → flygplanets axlar.** `ImuSensorBase` roterar kretsens axlar
med matrisen `ImuOrientation` (body = R · chip) till flygplanets axlar: X
mot nosen, Y åt vänster, Z uppåt. Matrisen tas:

- från **monteringskalibreringen** (kommandot `o`, lagras i NVS) – kortet
  kan sitta i vilken orientering som helst. Tre positioner: ”plant” ger Z-axeln
  (och horisonten – accelerometerns nollförskjutning viks in i den), ”nosen
  upp” ger X-axeln (den del av ”upp” som är vinkelrät mot Z), ”höger vinge
  ned” ger Y-axeln. Nosen från steg 2 och nosen från steg 3
  (Y × Z) måste stämma överens inom ~25°, annars lutade piloten åt fel
  håll – kalibreringen avvisas; resultatet är medelvärdet av de två
  skattningarna. Verifierat på 300 slumpmässiga monteringar
  (`test/test_imu_orientation`, fel < 0,1°);
- annars – från `Config::IMU_ROTATION_CW_DEG` (kortet med kretsen
  uppåt; värdet är vart *kretsens* X-axel pekar om nosen är ”klockan
  12”), och horisonten är läget vid start.

Vid varje gyrokalibrering (start, `i`) görs en **kontroll före flygning**:
gyrobrus < 0,5 °/s (stillhet; i vila ~0,08), |a| ≈ 1g, ”upp” inom 45°
från det lagrade (kortet har inte flyttats). Om den misslyckas –
`ImuSensor::getPreflightProblem()` ≠ nullptr: `ArmingManager` armerar inte
de stabiliserade lägena, och `Autopilot::imuReady()` = false (noll korrigeringar
i alla lägen, inklusive glidflykt vid förlorad förbindelse).

> På den nuvarande GY-521 (en MPU6500-klon) är kretsen lödd vriden 90°
> i förhållande till de tryckta pilarna: X-pilen i tryckningen = kretsens
> Y-axel. Därför är `IMU_ROTATION_CW_DEG = 90` utan monteringskalibrering.
> Kontrollen efter varje omflyttning: nosen upp → P ökar åt det positiva
> hållet, höger vinge ned → R åt det positiva hållet.

**2. Vinklar och hastigheter (`ImuData`) – flygtekniska tecken:**

| Storhet | ”+” betyder |
|---|---|
| `roll`, `gyroX` | höger vinge ned |
| `pitch`, `gyroY` | nosen upp |
| `yaw`, `gyroZ` | nosen åt höger (medurs sett ovanifrån) |

**3. Kommandot (`ControlCommand`, µs utslag, ±500 = fullt utslag):**

| Fält | ”+” betyder | Från spaken |
|---|---|---|
| `roll` | roll åt höger (höger skevroder upp, vänster ned) | CH1: 2000 = höger |
| `pitch` | nosen upp (höjdrodret upp) | CH2 med motsatt tecken: 2000 = bort från dig = nosen ned |
| `yaw` | nosen åt höger (sidroder och noshjul åt höger) | CH4: 2000 = höger |
| `flaps` | klaffar ned (båda skevrodren ned) | SwB (CH6): 0 eller `FLAPS_DEPLOYED_US`, mjukt över `FLAPS_TRANSITION_MS` |

PID:en beräknar `error = target − actual`: roll åt höger (roll > 0) → ett
negativt rollkommando → flygplanet rätar upp sig. Autopilotens korrigeringar
läggs till spakkommandot **före** mixern, med samma tecken.

**4. Kommando → PWM.** `ControlMixer::mix()` beräknar bakkantens
utslag för varje yta (skevroder: ned = ”+”, vänster = `flaps + roll`,
höger = `flaps − roll`; höjdroder: upp = ”+”; sidroder: höger = ”+”) och
omvandlar det till PWM `1500 ± utslag`, med omvänt tecken för servon med
`Config::*_REVERSED = true`. Standardvärdena återger firmwarens
tidigare beteende för spakarna. Kontrollen på det monterade flygplanet finns i
checklistan före flygning i [`PILOT_GUIDE.md`](PILOT_GUIDE.md). Reverseringen
ska ändras i `Config.h`, **inte på sändaren** – annars blir
spaken och autopiloten oense.

---

## RC-kanalkarta, ARM och failsafe

Källan är `include/config/Channels.h`. En FS-i6-sändare (10 kanaler,
mode 2) + en FS-iA6B-mottagare, iBUS 115200.

| Kanal | Reglage på sändaren | Namn | Syfte |
|---|---|---|---|
| CH1 | höger spak ←→ | `AILERON` | Roll |
| CH2 | höger spak ↑↓ | `ELEVATOR` | Tippning |
| CH3 | vänster spak ↑↓ | `THROTTLE` | Gas, fullt utslag; < 950 = mottagarens failsafe |
| CH4 | vänster spak ←→ | `RUDDER` | Sidroder + styrhjul (ett servo) |
| CH5 | SwA | `ARM` | ≥ 1750 = ARM (på FS-i6 är det brytaren ned, mot dig) |
| CH6 | SwB | `SWB` | klaffar som standard (≥ 1750 – utfällda) |
| CH7 | SwC (3 lägen) | `SWC` | läge som standard: < 1250 MANUAL, 1250–1749 STABILIZE, ≥ 1750 AUTO_TAKEOFF |
| CH8 | SwD | `SWD` | RTH som standard |
| CH9 | VrA | `VRA` | stabiliseringens styrka som standard |
| CH10 | VrB | `VRB` | marschfart som standard |

CH6–CH10 tilldelas med en enda rad i `include/config/Controls.h`
([AUTOPILOT_GUIDE.md](AUTOPILOT_GUIDE.md#tilldela-en-funktion-med-en-enda-rad)).

**ARM** (`ArmingManager`): brytaren går OFF→ON, gas < `THROTTLE_LOW_US`,
och sensorkontrollerna för det aktuella läget har godkänts. Annars nekas den,
med orsaken utskriven i Serial, och en ny cykel OFF→ON behövs. Att starta
kortet med brytaren redan på ON armerar inte. OFF – DISARM direkt.
Så länge planet inte är armerat tvingas gasen till ESC:n till `PWM_MIN`.

**Förlorad förbindelse** (`IBusReceiver::isSignalLost()`):

1. Inga ramar på mer än `RX_TIMEOUT_US` (500 ms) – en bruten tråd eller
   förlorad matning till mottagaren. Före den första ramen efter start räknas förbindelsen
   också som förlorad: kanalernas standardvärden (alla 1500) tas inte
   för sändarkommandon.
2. Gas < `RX_FAILSAFE_THROTTLE_US` (950) – den failsafe som ställts in i
   sändaren. **När sändaren tappas slutar FS-iA6B inte
   skicka ramar**, den upprepar de senaste värdena (verifierat på bänken), så
   utan en failsafe inställd i sändaren upptäcks den förlorade förbindelsen
   inte. Inställningen beskrivs i `PILOT_GUIDE.md`.

Vad som händer vid förlorad förbindelse (`FlightController::applyLinkLoss()`):

- **planet är armerat, GPS och en hempunkt finns**
  (`FAILSAFE_RTH`) – **hemflygning** med motor, cirkling över hempunkten; på
  OLED-skärmen – `FSRTH`, i loggen – `FAILSAFE_RTH`;
- **planet är armerat, ingen GPS** – **glidflykt**, motorn på
  `FAILSAFE_THROTTLE`: i alla lägen, även MANUAL, håller `Autopilot` rollen
  `FAILSAFE_GLIDE_ROLL_DEG` (0 – rakt, 10–20° – en cirkel över piloten)
  och tippningen `FAILSAFE_GLIDE_PITCH_DEG` (−3°, för att inte tappa fart
  utan motor), klaffarna fälls in; på OLED-skärmen – `GLIDE`, i
  loggen – läget `FAILSAFE_GLIDE`;
- **inte armerat** (på marken) eller IMU:n svarar inte – roderytorna
  går till neutralläge;
- läget och funktionerna byts inte från brytarna, sensorerna
  fortsätter att läsas. ARM nollställs inte – när förbindelsen återställts lyder
  flygplanet åter spakarna och det valda läget (automatisk start
  och handstart börjar bara om).

---

## Sensordata

Strukturerna finns i `include/sensors/SensorInterface.h`.

### `ImuData`

| Fält | Enhet | Betydelse |
|---|---|---|
| `gyroX`, `gyroY`, `gyroZ` | °/s | Vinkelhastigheter i flygplanets axlar, flygtekniska tecken (se ovan) |
| `accelX`, `accelY`, `accelZ` | g | Acceleration i flygplanets axlar: X mot nosen, Y åt vänster, Z uppåt |
| `roll`, `pitch` | ° | Komplementärfilter (α = 0,98, τ ≈ 0,1 s); de startar direkt från accelerometerns vinkel |
| `yaw` | ° | Gyrointegral, driver långsamt; startvärdet är kompasskursen |
| `temperature` | °C | Kretsens temperatur (formel för MPU6050 eller MPU6500) |
| `timestamp` | µs | `micros()` vid avläsningsögonblicket |

IMU-kalibrering (vid varje start och med kommandot `i`): 2 s orörligt,
gyrot → nollförskjutning, accelerometern → **det aktuella läget blir
horisonten**.

### `BarometerData`

| Fält | Enhet | Betydelse |
|---|---|---|
| `pressure` | Pa | Tryck |
| `temperature` | °C | Sensorns temperatur |
| `altitude` | m | Höjd **relativt kalibreringspunkten** (vid start); formel `44330·(1 − (P/P0)^0.1903)` |
| `verticalSpeed` | m/s | Höjdens derivata över de verkliga mätningarna (50 Hz) via ett lågpassfilter med τ = 0,5 s |
| `timestamp` | µs | Ögonblicket för den senaste nya mätningen |

### `MagData`

| Fält | Enhet | Betydelse |
|---|---|---|
| `magX`, `magY`, `magZ` | µT | Fältet efter hard-iron-kalibrering, i flygplanets axlar (`MAG_ROTATION_CW_DEG`) |
| `headingDegrees` | ° (0..360) | `atan2(magY, magX)`, utan lutningskompensation; avläsningens riktning har ännu inte verifierats på ett monterat flygplan |
| `timestamp` | µs | Avläsningsögonblicket (50 Hz) |

### `GpsData`

| Fält | Enhet | Betydelse |
|---|---|---|
| `latitude`, `longitude` | ° | Från UBX-NAV-PVT |
| `altitude` | m | Över havet (hMSL) |
| `groundSpeed`, `heading` | m/s, ° | Markhastighet och kurs över marken |
| `numSatellites`, `fixType` | – | 0 = ingen fix, 2 = 2D, 3 = 3D |
| `horizontalAccuracy`, `verticalAccuracy` | m | Modulens noggrannhetsskattningar |

**Vad `isAvailable()` betyder.** För I2C-sensorer – sensorn svarade vid
`begin()` **och** de senaste avläsningarna misslyckas inte i följd (MPU – ~0,1 s,
barometer och kompass – ~0,5 s utan svar). När en avläsning misslyckas
skrivs data inte över med skräp: de tidigare värdena står kvar och felräknaren
ökar (syns med kommandot `s`). För GPS – minst en giltig
NAV-PVT, och den senaste är inte äldre än `GPS_TIMEOUT_US`.

**Om en sensor saknas** (`nullptr` eller `isAvailable() == false`) ger `Autopilot`
inga korrigeringar, och flygplanet flygs som i MANUAL. `main.cpp`
kalibrerar bara de sensorer som svarade.

---

## Genomgång av FlightController::update()

Anropas från `loop()` var 2:a ms. Ordningen är prioriteten:

1. **`receiver.update()`** – tolkning av de ackumulerade iBUS-byten.
2. **Brytare** – `switches->update(rc)`, bara medan förbindelsen lever (i en
   failsafe-ram återspeglar kanalerna inte brytarna): läget (bara
   vid en ändring), funktioner, rattar.
3. **Pilotens gas** – `throttle.update(rc, receiverFailsafe)`.
4. **Spakar** – `mixer.fromSticks(rc)` × `Knob::RATES`; klaffar –
   `mixer.updateFlaps(target)` (broms, brytare, ratt; utan förbindelse – 0).
5. **Sensorer och autopilot** – `autopilot->update(armed, linkLost, pilotThrottle, sticks)`
   **alltid**, även utan förbindelse: vinkelfiltren får inte frysa. Så länge
   planet inte är armerat körs PID:en (roderytorna reagerar på lutning – praktiskt
   på skrivbordet), men integratorn hålls på noll. Utan förbindelse och
   armerat – failsafe RTH eller glidflykt.
6. **Summer** – `Beeper`.
7. **Förlorad förbindelse** – `applyLinkLoss()`: när armerat – roderytorna och
   gasen följer autopilotens failsafe-kommando, annars neutralläge och
   motorn av; `return`. Absolut prioritet över allt nedanför.
8. **ARM** – `arming.update(rc, false)`.
9. **Kommando** – `autopilot->getCommand()`: i de stabiliserade lägena är spaken
   den önskade vinkeln, och autopiloten ger de slutliga
   roderkommandona.
10. **Mixer** – `mixer.mix(command)` → PWM för skevrodren (flaps + roll),
    höjdrodret och sidrodret, med hänsyn till reverseringen.
11. **Gas** – `autopilot->applyThrottle(pilotThrottle)`: pilotens
    gas, autopilotens gas eller det högsta av de två (automatisk
    start). Därefter, om inte armerat eller `MOTOR_KILL` – tvingad till `PWM_MIN`. Den här
    kontrollen kommer sist så att inget läge kan smyga gasen förbi ARM.
12. **AUX** – last (`PAYLOAD_DROP`) och kamera (`CAMERA_TILT`, `CAMERA_STAB`).
13. **`outputs.write(output)`** – PWM till de 7 utgångarna.

---

## Webbpanelens HTTP-API

Implementeringen är `include/telemetry/WebDebugServer.h`. Åtkomstpunkten:
SSID `OpenPlane-Debug`, lösenord `12345678`, adress `http://192.168.4.1`.

### `GET /api/status`

```json
{
  "rc": [1500, 1500, 1000, 1500, 1000, 1000, 1000, 1000, 1000, 1500],
  "armed": false,
  "failsafe": false,
  "outputs": {
    "aileronLeft":  { "us": 1500, "attached": true },
    "aileronRight": { "us": 1500, "attached": true },
    "elevator":     { "us": 1500, "attached": true },
    "rudder":       { "us": 1500, "attached": true },
    "esc":          { "us": 1000, "attached": true },
    "aux1":         { "us": 1000, "attached": true },
    "aux2":         { "us": 1500, "attached": true }
  },
  "flapsUs": 0,
  "imu":  { "attached": true, "available": true, "roll": 0.12, "pitch": -0.40, "yaw": 38.50 },
  "baro": { "attached": true, "available": true, "altitude": 0.05, "climb": 0.01 },
  "mag":  { "attached": true, "available": true, "heading": 41.9 },
  "gps":  { "attached": true, "available": true, "fix": 3, "numSV": 12, "lat": 55.750000, "lon": 37.610000, "alt": 150.0 },
  "airspeed": { "attached": true, "available": true, "ias": 14.2, "tas": 14.3, "dp": 123.4 },
  "autopilot": {
    "attached": true, "mode": 1, "modeName": "STABILIZE",
    "desiredRoll": 0.0, "desiredPitch": 0.0, "targetAlt": 0.0,
    "rollCorr": 0.0, "pitchCorr": 0.0, "throttleCorr": 0.0,
    "kpRoll": 5.000, "kiRoll": 0.500, "kdRoll": 0.500,
    "kpPitch": 5.000, "kiPitch": 0.500, "kdPitch": 0.500,
    "nav": { "gps": true, "home": true, "homeDist": 120, "homeBearing": 185,
             "course": 90, "targetCourse": 90, "speed": 14.3, "fence": false, "stall": false },
    "features": ["FLAPS"]
  }
}
```

- `attached` – objektet finns i bygget; `available` – sensorn
  svarar verkligen. Datafälten läggs till **bara** när `available: true`.
- `outputs.*.attached` – mikrokontrollern har tilldelat en LEDC-kanal och ett stift;
  om ett fysiskt servo är anslutet kan inte ses från mjukvaran (för att
  kontrollera pulsen, använd konsolen, kommandot `p`).
- `rollCorr`/`pitchCorr` – autopilotens slutliga kommando minus spakarna,
  µs. `throttleCorr` – autopilotens gas, % (0 medan gasen ligger
  hos piloten).
- `nav` – navigering: hempunkt, avståndet och bäringen till den, kursen och
  målkursen, den hastighet som används för navigering (pitotrör / GPS),
  geofencen, överstegring; `features` – de brytarfunktioner som är påslagna.

### `POST /api/setmode`

`{ "mode": 1 }` – numret på `AutopilotMode`: `0` MANUAL, `1` STABILIZE, `2`
AUTO_TAKEOFF, `3` ALT_HOLD, `4` ACRO, `5` CRUISE, `6` LOITER, `7` RTH, `8`
LAUNCH, `9` AUTO_LAND, `10` SOARING, `11` RESCUE. Läget gäller tills
piloten slår om lägesbrytaren.

### `POST /api/setpid`

`{ "kpRoll": 5, "kiRoll": 0.5, "kdRoll": 0.5 }` – valfria av fälten `kpRoll`,
`kiRoll`, `kdRoll`, `kpPitch`, `kiPitch`, `kdPitch`; utelämnade behåller sina
tidigare värden.

Båda kommandona tillämpas av flygslingan i nästa cykel (se
[FreeRTOS-uppgifter](#freertos-uppgifter-och-styrslingan)).

### `GET /`

HTML-panelen: staplar för de 10 kanalerna, ARM/förbindelse, utgångarna,
sensorerna, lägesknappar, PID-formuläret. Den frågar `/api/status` var 200:e ms.

---

## Konsol och diagnostik

Portmonitorn – 115200, ”COM”-kontakten. Implementeringen är
`DebugConsole` och `DebugLogger` ([referens](reference/telemetry.md)). Tangenterna
verkar direkt, Enter krävs inte; kalibreringarna och `p` blockerar
slingan och är därför bara tillgängliga utan ARM.

| Tangent | Vad den gör |
|---|---|
| `h` / `?` | Huvudmeny |
| `l` | Menyn ”vad som ska skrivas till loggen” (kanaler, lägen, period) |
| mellanslag | Pausa loggen / återuppta |
| `s` | `printStatus()` för alla sensorer: data, räknare för bussfel, kalibreringar, kontrollen före flygning |
| `i` | Gyrokalibrering + kontroll före flygning (2 s orörligt) |
| `o` | Kalibrering av IMU-monteringen med tre positioner, sparas i NVS |
| `m` | Kompasskalibrering (15 s rotation), sparas i NVS |
| `p` | Självtest av utgångar: den verkliga pulsen på varje stift mot den förväntade |

Loggen är uppdelad i kanaler (`STAT`, `RC`, `OUT`, `ATT`, `AP`, `ALT`, `MAG`,
`GPS`, `IMU`, `SYS`), var och en med ett läge ”av / vid ändring / kontinuerligt”;
inställningarna lagras i NVS och skrivs när menyn stängs, bara utan
ARM. Som standard är `STAT` (vid ändring) och `SYS` (var 10:e s) påslagna:

```
STAT RX=OK ARM=NO MODE=STABILIZE FLAPS=UP IMU=OK BARO=OK
SYS  loop 500 Hz, avg 700 us, max 1400 us (worst over 10 s) | iBUS ok=... crc_err=... | heap ... KB | uptime ... s
```

Formaten för alla kanaler finns i [referensen](reference/telemetry.md#debuglogger).

---

## Val av kort och stiftbeläggning

| Kommando | `board` | Makro | Status |
|---|---|---|---|
| `pio run -e esp32-s3` | `esp32-s3-devkitc-1` + N16R8 (`qio_opi`, 16 MB) | `BOARD_ESP32_S3` | **Huvudkort, standard.** Provat på bänken med alla sensorer |
| `pio run -e esp32-c3` | `esp32-c3-devkitm-1` | `BOARD_ESP32_C3` | Den gamla prototypen, flugen med manuell styrning |
| `pio run -e esp32-dev` | `esp32dev` | `BOARD_ESP32_CLASSIC` | För bänken, stiftbeläggningen har inte provats på hårdvara |
| `pio run -e stm32h743` | `weact_mini_h743vitx` | `BOARD_STM32H743` | STM32H743VIT6: den fullständiga firmwaren + MAVLink + en svart låda på SD-kort; provad på ett naket kort ([nedan](#stm32h743)) |
| `pio run -e stm32h743-devebox` | `devebox_h743vitx` | `BOARD_STM32H743` | Samma sak på DevEBox H743: konsolen är USB CDC, flashning via DFU |

| Syfte | ESP32-S3 (bänk) | ESP32-C3 | ESP32 classic |
|---|---|---|---|
| Skevroder vänster / höger | GPIO4 / GPIO5 | GPIO5 / GPIO4 | GPIO13 / GPIO14 |
| Höjdroder / ESC | GPIO6 / GPIO7 | GPIO6 / GPIO7 | GPIO27 / GPIO26 |
| Sidroder | GPIO18 | – (inget stift) | GPIO25 |
| iBUS RX | GPIO17 | GPIO8 | GPIO16 |
| Sensorernas I2C SDA / SCL | GPIO41 / GPIO42 | GPIO1 / GPIO3 | GPIO21 / GPIO22 |
| OLED I2C SDA / SCL | GPIO1 / GPIO2 | – | – |
| SPI SCK / MISO / MOSI | GPIO12 / 13 / 11 | GPIO0 / 10 / 20 | GPIO18 / 19 / 23 |
| SPI CS ICM42688 / BMP388 | GPIO14 / GPIO21 | GPIO21 / GPIO2 ⚠️ | GPIO32 / GPIO5 |
| GPS RX / TX | GPIO39 / GPIO40 (UART2) | GPIO9 ⚠️ / inget (UART0) | GPIO4 / GPIO17 (UART2) |
| Serial | UART0 → ”COM”-kontakten | USB-CDC | UART0 |

- **ESP32-S3 N16R8:** GPIO33–37 är upptagna av oktal PSRAM, 26–32 av
  flash, 19/20 av USB, 43/44 av Serial, 48 är RGB-lysdioden; 0/3/45/46 är
  strapping-stift.
- **ESP32-C3:** skevrodren på GPIO4/5 är omkastade jämfört med S3. Det
  finns inte tillräckligt med stift för hela uppsättningen: BMP388:s CS och GPS:ens RX sitter på
  strapping-stift, GPS:en har ingen TX (bara mottagning, ingen UBX-CFG). Detaljer finns
  i `Config.h`.

### STM32H743

STM32H743VIT6 (Cortex-M7 480 MHz, 2 MB flash, 1 MB RAM) kör den
**fullständiga firmwaren**: samma sensorer, autopilot, brytare, konsol och skärm
som på ESP32-S3, plus MAVLink-telemetri och en svart låda på SD-kort. Den
byggs, klarar cppcheck och alla native-tester av den gemensamma koden. På
hårdvara har **DevEBox H743-kortet utan sensorer** provats: uppstart,
konsolen via USB, SD-kortet, den svarta lådan –
[TESTING.md](TESTING.md#tester-på-stm32-kortet) – samt iBUS, ARM och PWM
till servona och motorn: styrning från sändaren i manuellt läge (på
video). Sensorerna kopplas nu in till STM32. **Huvudkortet är STM32H743 (DevEBox)**; ESP32-S3 är det tidigare huvudkortet, och det klarade bänken med alla sensorer.

- **HAL** – `include/hal/stm32/`: `Stm32Board` (samma API som `Esp32Board`,
  plus `telemetryUart()`), `Stm32I2CBus`, `Stm32SpiBus`, `Stm32UartPort`,
  `Stm32ServoOutput` (hårdvaru-PWM från `HardwareTimer`, en timer för
  flera utgångar). I detalj – [reference/hal.md](reference/hal.md#implementering-för-stm32h743).
- **Inställningar och kalibreringar** – inte NVS utan en `KeyValueStore` i den sista
  flashsektorn (`include/storage/`, `hal/stm32/Stm32FlashStorage.h`).
  Projektets kod skriver fortfarande `#include <Preferences.h>`: i env `stm32h743`
  ligger katalogen `include/hal/stm32/compat/` på `-I`, och där finns en
  `Preferences` med samma API. Avbilden bär en CRC32: en
  korrupt (strömmen gick under raderingen) läses som tom. Flashskrivningen
  sker i en bakgrundsuppgift: radering av en sektor på 128 KB tar sekunder,
  men sektorn ligger i bank 2 medan koden körs från bank 1, och
  flyguppgiften avbryter bakgrundsuppgiften utan att stanna.
- **Uppgifter** – FreeRTOS från biblioteket STM32duino FreeRTOS, en enda kärna,
  preemption efter prioritet (`hal/Rtos.h`): `flight` (5) – flygslingan,
  MAVLink, logg, konsol; `oled` (1) och `storage` (1) – i bakgrunden;
  `bbox` (2) – skrivning av den svarta lådan till SD-kortet.
- **Den svarta lådan på SD-kortet** – SDMMC1, 4 bitar, 24 MHz
  (`hal/stm32/Stm32SdCard.h`, stiften i `src/stm32/sd_msp.cpp`). Kortet
  förblir ett vanligt FAT32: en i förväg skapad fil `BLACKBOX.BIN` ligger på det,
  firmwaren skriver råa block inuti den och rör inte själva filsystemet
  (`storage/Fat32File.h` är skrivskyddad). Förberedelse av kortet och
  hämtning – [BLACKBOX.md](BLACKBOX.md#sd-kort-stm32h743).
- **Telemetri** – MAVLink 2 på UART4 (`telemetry/MavlinkTelemetry.h`) i stället
  för Wi-Fi-panelen: QGroundControl / Mission Planner, byte av läge
  och PID från marken. I detalj –
  [AUTOPILOT_GUIDE.md](AUTOPILOT_GUIDE.md#markstation-wi-fi-panel-och-mavlink).
- **Stiftbeläggning** – blocket `BOARD_STM32H743` i `Config.h`, stiften valda
  bland de lediga på WeAct MiniSTM32H743VITx och kontrollerade mot
  STM32duinos tabeller:

| Syfte | STM32H743 | Kringutrustning |
|---|---|---|
| Skevroder vänster / höger | PA0 / PA1 | TIM2_CH1 / CH2 |
| Höjdroder / ESC | PA2 / PA3 | TIM2_CH3 / CH4 |
| Sidroder | PD14 | TIM4_CH3 |
| AUX1 (last) / AUX2 (kamera) | PD15 / PE9 | TIM4_CH4 / TIM1_CH1 |
| iBUS RX (TX – reserv) | PE7 (PE8) | UART7 |
| Sensorernas I2C SDA / SCL | PB11 / PB10 | I2C2 |
| OLED I2C SDA / SCL | PB9 / PB8 | I2C1 |
| SPI SCK / MISO / MOSI | PB13 / PB14 / PB15 | SPI2 |
| SPI CS IMU / barometer | PB12 / PD10 | GPIO |
| GPS RX / TX | PD9 / PD8 | USART3 |
| Radiomodem MAVLink RX / TX | PD0 / PD1 | UART4 |
| Summer | PE15 | GPIO |
| Serial | PA10 / PA9 | LPUART1 |

- **DevEBox H743 (MCUDEV)** – env `stm32h743-devebox`: samma kod, en egen
  kärnvariant, konsolen via USB-C som en virtuell COM-port (CDC) – ingen
  USB-UART behövs. Den första flashningen sker via USB genom den inbyggda
  bootloadern (DFU):
  1. Windows: installera WinUSB-drivrutinen för ”STM32 BOOTLOADER” en gång
     ([Zadig](https://zadig.akeo.ie): DFU in FS Mode → WinUSB → Install Driver).
  2. Anslut stiftet **BT0** (BOOT0) till **3V3** med en tråd, tryck på och
     släpp **RST**: kortet är i DFU-läge (DevEBox har ingen BOOT0-
     knapp).
  3. `pio run -e stm32h743-devebox -t upload` (`upload_protocol = dfu`).
  4. BT0-tråden kan tas bort – firmwaren startar av sig själv.

  Därefter behövs inte tråden: tangenten **`D`** i konsolen (från valfri
  meny, inte under ARM) startar om kortet i bootloadern: en markör i
  RAM → återställning → ett hopp in i systemminnet innan klockorna konfigureras
  (`src/stm32/bootloader.cpp`). Att hoppa direkt från körande firmware hänger sig
  på H7 – verifierat på kortet, därav de två stegen. En öppen konsol
  (USB CDC) behövs; om kortet inte svarar – RST med BT0-tråden
  på plats.
- **Ingångspunkt** – `src/stm32/main.cpp` (utesluten från ESP32-byggena via
  `build_src_filter`). Objekten är desamma som i `src/main.cpp`; i stället
  för `loop()` finns uppgifter, och `vTaskStartScheduler()` står i slutet av
  `setup()`.
- **Kortets första start:** `pio run -e stm32h743 -t upload` (ST-Link),
  monitorn på LPUART1 via en USB-UART; `b` – om sensorerna syns
  på bussarna, `s` – sensorstatus, `p` – pulser på utgångarna
  (ta av propellern), sedan sändaren och QGroundControl via
  radiomodemet.

---

## Hur man lägger till en ny sensor

### A) En annan krets i en befintlig kategori (IMU, barometer, kompass)

Den gemensamma koden är redan skriven i basklasserna – en kretsdrivrutin blir
liten:

1. Skapa `include/sensors/<kategori>/<Namn>_Sensor.h` och ärv från
   `ImuSensorBase` / `BarometerBase` / `MagnetometerBase`. Konstruktorn
   tar en `IRegisterDevice&` – drivrutinen vet inte om det är I2C
   eller SPI.
2. Implementera:
   - `begin()` – `device.begin()`, kontrollera kretsens ID, skriv registren,
     anropa `setAvailable(true/false)`;
   - IMU: `readSample()` (rå accel/gyro/temp i kretsens axlar),
     `accelLsbPerG()`, `gyroLsbPerDps()`, `temperatureC()`;
   - barometer: `isNewSampleReady()` (en klar-flagga eller helt enkelt `true`) och
     `readSample()` (tryck i Pa, temperatur i °C), avläsningsperioden
     anges i baskonstruktorn;
   - kompass: `readRaw()` (X/Y/Z i kretsens axlar) och
     `lsbPerMicroTesla()`, NVS-namnrymden för kalibreringen anges i
     baskonstruktorn.
3. Om kretsen behöver en dummybyte före data över SPI eller en särskild
   frekvens – lägg till en statisk fabrik `spiDevice(bus, cs)`, som den i
   `BMP388_Sensor`.
4. En gren i `SensorSelection.h`: `#define SENSOR_<KATEGORI>_<NAMN>`,
   `using Selected... = ...;` och `#define SELECTED_..._DEVICE(board) ...`
   (`I2cRegisterDevice(board.i2c(), address)` eller SPI-fabriken). `main.cpp`
   rörs inte när sensorn byts.
5. Kontrollera bygget med den nya sensorn utan att redigera filen – med en
   flagga: `PLATFORMIO_BUILD_FLAGS="-DSENSOR_BARO=SENSOR_BARO_<NAMN>" pio run`,
   sedan alla tre miljöerna, sedan på hårdvara.

### B) En ny kategori

1. Datastrukturen och gränssnittet läggs i `SensorInterface.h`, efter förebild av
   `GpsSensor`/`GpsData`.
2. Om kategorin har gemensam logik (filter, kalibrering) – en basklass
   efter förebild av `BarometerBase`.
3. En nullbar pekare i konstruktorn för `Autopilot` (ingen sensor – inga effekter,
   snarare än en krasch) och fält i `GET /api/status` med ett
   `attached`/`available`-par.

### En ny buss eller kringutrustning

Ett nytt gränssnitt i `include/hal/`, en implementering i `include/hal/esp32/`
och i `include/hal/stm32/`, åtkomst via `IBoard`.

---

## Hur man lägger till ett nytt autopilotläge

1. Ett värde i `enum AutopilotMode` (`autopilot/AutopilotTypes.h`, före
   `MODE_COUNT`), ett namn och ett kort namn (upp till 5 tecken, för OLED-skärmen)
   i `AutopilotNames::mode()` / `modeShort()`.
2. En hanterare `run<Mode>()` och en gren i `Autopilot::runMode()`; de initiala
   målen (kurs, höjd, cirkelns mittpunkt) läggs i `initializeMode()`. Läget
   sätter `desiredRoll`/`desiredPitch` och anropar `stabilizeOrManual()`
   (utan IMU har piloten roderytorna) eller
   `stabilizeOrNeutral()` (utan IMU – neutralläge). Utan den nödvändiga
   sensorn – säkert beteende, inte en krasch. Integratorn ackumulerar bara när
   `armed`.
3. Gas: `throttleMode` (`PILOT` / `AUTO` / `AT_LEAST`) och
   `autoThrottlePct`, eller `autoThrottle()` – marschgasen från
   ratten / från pitotröret. `FlightController` ändras inte.
4. På sändaren – en enda rad i `config/Controls.h`
   (`Bind::mode(Channels::SWD, MODE_NEW)`). Panelen och MAVLink plockar upp
   läget efter dess nummer; för MAVLink – det närmaste ArduPlane-läget i
   `MavlinkModes::toCustomMode()` / `fromCustomMode()`.
5. Om läget behöver sensorer för ARM – `ArmingManager`.
6. Tester: reaktionen på varje sensor – `test/native/test_autopilot_modes`,
   flygning i sluten slinga – ett scenario i `test/native/test_sim` (flygplansmodellen
   `helpers/PlaneSim.h`, riggen `helpers/SimHarness.h`). Sedan – skrivbordet
   utan propeller: roderytorna måste reagera på lutning
   i riktning mot plant läge.
7. Ett avsnitt i [AUTOPILOT_GUIDE.md](AUTOPILOT_GUIDE.md).

---

## Återkoppling (förarbete, inte ansluten)

`include/autopilot/feedback/` är nästa steg för autopiloten. **Varken
`FlightController`, `Autopilot` eller `main.cpp` inkluderar de här filerna:**
det finns ännu ingen prototyp för flygprov, och firmwaren fungerar utan
dem. De verifieras med en simulering i sluten slinga (`test/test_feedback/`)
direkt på kortet.

### Varför

I dag är `Autopilot` en PID på vinkeln: fel × förstärkning = roderyta. Den
vet inte vad det blev av det på flygplanet, och förstärkningarna är rätt
bara för en hastighet: vid låg fart är ytan svagare och PID:en
korrigerar för lite, vid hög fart korrigerar den för mycket. Återkopplingen sluter slingan över
**flygplanets respons**:

- ytan gav utslag men flygplanet roterar långsammare än det behövs – lägg
  på mer, tills det kommer dit;
- hur mycket roderyta som behövs mäts under flygning och räknas om med
  hastigheten;
- flygplanet roterar åt fel håll – tecknet är förväxlat, vänd det och
  kontrollera;
- vinkeln har rätats upp men farten sjunker – gas upp och nosen
  ned, innan flygplanet steglar;
- start och landning – i faser, utifrån vad sensorerna visar.

### Moduler

| Fil | Vad den gör |
|---|---|
| `FlightSnapshot.h` | Allt som återkopplingen vet om flygplanet under en cykel. Den enda indatan: modulerna läser inte sensorerna och RC direkt, så de kan köras på en simulering och på loggar |
| `FeedbackOutput.h` | Utdatan för en cykel: roderutslag per axel, om axeln är påslagen, axelns tecken, gas (satt / inte under), orsaken |
| `FeedbackConfig.h` | Alla konstanter (de flyttas till `Config.h` vid anslutning) |
| `SpeedEstimator.h` | Hastighet (pitotrör > GPS) och longitudinell acceleration från IMU:n: `dV/dt = g·(ax − sin θ)` – ”farten sjunker” syns även utan lufthastighetssensor |
| `AirborneDetector.h` | I luften / på marken: inlärning, ackumulering av integralen och sökandet efter överstegring är bara meningsfulla under flygning |
| `ControlEffectivenessEstimator.h` | Lär sig för varje axel modellen `ε = b·u(t−delay) + a·ω + c` med rekursiva minsta kvadrater |
| `AdaptiveRateController.h` | En kaskad vinkel → vinkelhastighet → vinkelacceleration → roderyta genom den inlärda modellen |
| `StallGuard.h` | Skydd mot fartförlust och överstegring |
| `TakeoffSequencer.h`, `LandingSequencer.h`, `PhaseTargets.h` | Start (från bana eller för hand) och landning i faser, utifrån sensorerna |
| `FeedbackSupervisor.h` | Allt tillsammans: ordningen inom en cykel, prioriteterna, `requestTakeoff()`/`requestLanding()`/`cancelPhase()`, `printStatus()`, anslutningsplanen |
| `FeedbackModules.h` | En enda include för allt |

### Hur det fungerar

**Roderytornas verkan.** Axelmodellen: vinkelacceleration
`ε = b·u + a·ω + c`. `b` är hur många °/s² 1 µs roderyta ger (tecknet är
responsens riktning), `a` är dämpning (luften bromsar rotationen;
utan den termen skulle skattningen av `b` gå mot noll under en jämn
rotation), `c` är ett konstant moment (tyngdpunkt, trim, propeller). En
rodrytas kraft ∝ ρV², så `b` lärs in vid en referenshastighet och
multipliceras med `(V/Vref)²`: flygplanet ökar farten – ytan ”blir
starkare” direkt utan ny inlärning. Den indikerade lufthastigheten från pitotröret
innehåller redan luftens densitet, så höjden tas med av sig
själv; utan lufthastighetssensor är skalan 1, och `b` lärs in
direkt.

Data tas över intervall på 20 ms: den genomsnittliga accelerationen över ett
intervall är skillnaden i gyro vid ändarna / längden, och den
motsvarar det genomsnittliga roderutslaget och vinkelhastigheten över samma
intervall (roderytan – med fördröjningen `RESPONSE_DELAY_MS`). Sedan passerar båda sidor
av ekvationen genom samma lågpassfilter på 2 Hz: sambandet
ändras inte, medan de höga frekvenserna, där modellen med ”ren fördröjning” ljuger
på grund av servots tröghet, tas bort. Inlärning är möjlig bara i luften
och bara medan roderytan ”skakas” (ett utslag ≥ `MIN_EXCITATION_US`
över ~0,3 s); pilotens spakar skakar också, så skattningen lär sig även
i MANUAL.

**Regulatorn.** Tre steg, axel för axel:

```
ω* = ANGLE_GAIN · (target − angle)              "nosen är 10° ned – höj den med 40°/s"
ε* = (ω* − ω + I) / RATE_TAU,  I += Ki·(ω* − ω)  "roterar långsammare än det behövs – korrigera"
surface = (ε* − a·ω − c) / b                    genom den inlärda modellen
```

Integralen `I` lagras i °/s, inte i µs roderyta – så den förblir
korrekt när skattningen av `b` ändras. På marken är integralen
fryst (utom för kursen under startrullningen / utrullningen), och vid
ytans gräns ackumulerar den inte mot gränsen. En koordinerad sväng
tas med i beräkningen (om farten är känd): i en krängning behöver tippningen
`g·sin φ·tg φ / V` och giren `g·sin φ / V`.

**Axeltecken – bara på marken.** Under flygning stängs axlarna varken av
eller vänds: IMU-monteringen bestäms av kalibreringen `o` och
kontrollen vid start, och roderytornas riktningar av pilotens kontroll
före flygning. Indirekta tecken i luften (en avgång, en spinn, manövrer, byar) kan
lura, och en avstängd eller vänd axel i ett sådant ögonblick kostar flygplanet.
Om skattningen av `b` för en axel säkert är negativ är det bara en
varning i `reason` (”reagerar bakvänt på roderytan? kontrollera på
marken”); en negativ skattning går inte in i regulatorn – axeln
arbetar med a priori-modellen.

**Överstegringsskydd.** Två nivåer. *LowEnergy* – farten sjunker snabbt
med höjd nos, eller är nära överstegringen (< 1,25·Vs), eller höjdrodret
har förlorat verkan: gas ≥ 80 %, tippning ≤ 5°. *Stall* – farten är
under överstegringsfarten, nosen faller mot höjdrodret, vingen faller mot
skevrodren vid låg energi: full gas, nosen ned, krängning ≤ 10°, skevrodren
begränsade (ett stort skevroderutslag får vingspetsen att stegla). Åtgärderna släpps med
hysteres (fart ≥ 1,5·Vs). Vid förlorad förbindelse rörs inte gasen, och
alldeles nära marken (flaren, utrullningen) är skyddet avstängt –
landning är i sig en kontrollerad överstegring.

**Start.** `WaitThrottle` (motorn står still) → piloten gav gas
≥ 50 % → `GroundRoll` (full gas, vingarna plana, kursen hålls av
sidrodret och hjulet, höjdrodret fritt) → lättningsfart eller en tidsgräns
utan fartsensor → `Climb` (12°, full gas) → höjd 30 m →
`Complete`. För hand (`TAKEOFF_HAND_LAUNCH`), i stället för rullningen – `WaitLaunch`:
motorn startar först efter kastet (longitudinell acceleration ≥ 1g). Gasen
dragen tillbaka före lättning – avbryt.

**Landning.** `Approach` (gas 25 %, sjunkning 1 m/s – tippningen från
felet i vertikal hastighet, krängningen från piloten ≤ 20°) → höjd 2 m →
`Flare` (gas 0, sjunkningen dämpas till 0,3 m/s enligt samma regel) →
stöt i accelerometern eller ”lågt och roterar inte” → `Rollout` (kurs
med hjulet) → `Complete`. Pilotens gas ≥ 80 % – pådrag och ny inflygning. Flaren
behöver en avståndsmätare: barometern kan slå fel med en meter.

**Prioriteter** (`FeedbackSupervisor`): inte armerat > överstegringsskydd >
start/landning > lägets mål. Vid förlorad förbindelse avbryts faserna, och
stabiliseringen utför målen för glidflykten i failsafe.

### Simulering

`test/test_feedback/test_main.cpp` (på en dator: `pio test -e native -f test_feedback`) – en flygplansmodell (oberoende axlar,
servofördröjning och tröghet, roderytornas verkan ∝ V², dämpning ∝ V, konstanta
moment, lyftkraft via anfallsvinkeln från farten, överstegring, landningsställ med
ett styrhjul) och 10 scenarier:

| Scenario | Vad som kontrolleras |
|---|---|
| Återhämtning från 30° krängning / −15° tippning med ett konstant moment | Upprätning och ”fortsätt korrigera”: integralen hittar trimmet själv |
| Skakning ±15° vid 14 och 20 m/s, utan fartsensor | Skattningen av `b` konvergerar mot det sanna värdet och skalas om med farten |
| Ett förväxlat skevroder, piloten gungar vingarna i MANUAL | Skattningen av `b` är negativ → bara en varning, axeln stängs inte av |
| 30 s turbulens | Byar motverkas, krängningen går inte över 10° |
| Nosen 15° vid 20 % gas (med fartsensor och utan) | Farten sjunker inte till överstegring |
| Start från bana med propellerns reaktionsmoment | Faser, höjd, kurs under rullningen |
| Landning från 15 m | Faser, ingen gas nära marken, en mjuk sättning |
| Förlorad förbindelse under startrullningen; inte armerat; MANUAL | Avbrott, gasen rörs inte, roderytorna stannar hos piloten |

Modellen är grov – den kontrollerar logiken och tecknen, inte justeringen för en
specifik flygplansstomme.

```bash
pio test -e native -f test_feedback      # på en dator, på sekunder
pio test -e esp32-s3 -f test_feedback    # flashar testfirmwaren och kör den
pio run -t upload                        # återställ den vanliga firmwaren
```

### Anslutningsplan

1. `FlightController::update()` fyller, efter avläsning av sensorerna och beräkning av
   kommandona, i en `FlightSnapshot` och anropar
   `FeedbackSupervisor::update()`. Först – **skuggläge**: utdatan går
   bara till loggen (`printStatus()`) och till panelen, inte till
   roderytorna. Under flygning med manuell styrning måste skattningen av `b` för varje axel
   vara positiv och växa med farten.
2. På marken, flygplanet i händerna, STABILIZE: luta det – roderytorna
   motverkar.
3. En axel i taget: `deflectionUs` i stället för
   `Autopilot::getRollCorrection()` (först bara roll), sedan tippning.
4. Gas: `throttleOverridePercent`/`throttleFloorPercent` – efter
   `Autopilot::applyThrottle()`, före failsafe (failsafe går före
   allt).
5. Start/landning – på en ledig brytare; ta bort läget `AUTO_TAKEOFF` från
   `Autopilot`.
6. Konstanterna i `FeedbackConfig` – till `Config.h`; lufthastighetssensorn – en
   implementering av `AirspeedSensor` och en kategori i `SensorSelection.h`.

---

## Hur man lägger till ett nytt kort

1. `[env:<namn>]` i `platformio.ini` med en unik `-D BOARD_ESP32_<NAMN>`.
2. Ett block `#elif defined(BOARD_ESP32_<NAMN>)` i `Config.h` med alla
   stift, inklusive `PIN_I2C2_SDA/SCL` (−1 om det inte finns någon OLED). Räkna ut
   GPIO-budgeten i förväg: flash/PSRAM/USB/strapping.
3. Servoutgångarna behöver 5 LEDC-kanaler – varje ESP32 har dem. Om det inte finns
   något stift för sidrodret – `PIN_RUDDER = -1`, och utgången stängs helt
   enkelt av.
4. Ändra inte `default_envs` förrän kortet har provats på hårdvara;
   ange uttryckligen i commiten om stiftbeläggningen inte har provats.

---

## Kommandon för bygge, uppladdning och monitor

```bash
pio run                        # bygg standardkortet (stm32h743-devebox)
pio run -t upload              # ladda upp
pio device monitor             # monitor, 115200
pio run -e esp32-s3 -e esp32-c3 -e esp32-dev -e stm32h743   # kontrollera att alla kort byggs
```

- **ESP32-S3:** uppladdning och Serial går via ”COM”-kontakten (CH343).
  Om bryggan hänger sig (Windows svarar ”enheten fungerar inte” –
  det kan hända på grund av störningar från ESC:n) hjälper det att ansluta
  kabeln på nytt; du kan också ladda upp via ”USB”-kontakten (den inbyggda
  USB-JTAG): `pio run -t upload --upload-port <USB COM-port>`.
- Medan portmonitorn är öppen fungerar inte uppladdning till samma port.
- `lib_deps`: `olikraus/U8g2` (OLED) är det enda externa biblioteket.
- `test/` – i detalj i [`TESTING.md`](TESTING.md):
  - `pio test -e native -e native-stm32` – 387 tester på en dator (hårdvaruattrapper
    i `test/native/support/`), täckning – `gcovr`;
  - `pio test -e esp32-s3` – `test_feedback/` (återkopplingssimuleringen
    i sluten slinga) och `test_imu_orientation/` på själva kortet; var och en
    flashar en testfirmware, ladda efteråt upp den vanliga med
    `pio run -t upload`.
- Statisk analys: `pio check -e esp32-s3` (cppcheck), `pio check -e stm32h743` (cppcheck över
  `hal/stm32/` och `src/stm32/`) och `tools/clang-tidy.sh`
  (profilen `.clang-tidy`).

---

## Kända begränsningar

- **Autopiloten har inte provats under flygning.** På skrivbordet har tecknen
  verifierats live (lutning → korrigering mot plant läge), PID-förstärkningarna är
  startvärden.
- **STABILIZE är upprätning ovanpå spakarna**, inte ett ”vinkelläge”
  (FBWA) där spaken anger roll-/tippvinkeln. Piloten och
  autopiloten adderas.
- **Glidflykt vid förlorad förbindelse har inte provats under flygning.**
  Vinklarna `FAILSAFE_GLIDE_*` är startvärden; tippningen −3° är vald för
  en specifik flygplansstomme (nosen får varken stiga till överstegring eller dyka).
- **Horisonten.** Med monteringskalibreringen (`o`) – från den (NVS);
  accelerometerns nollförskjutning driver med temperaturen (~1–2° per 20 °C), om
  horisonten har ”drivit” – upprepa `o`. Utan den – läget vid start
  (slå på strömmen när flygplanet står plant).
- **Kompassens montering** anges fortfarande av `MAG_ROTATION_CW_DEG` (den
  positionsbaserade kalibreringen påverkar den inte).
- **Kompass:** kursen är utan lutningskompensation, avläsningens
  riktning har inte verifierats på ett monterat flygplan, och kalibreringen
  måste göras i själva flygplanet. Inget läge använder kursen ännu.
- **GPS** används inte för navigering; på ESP32-C3 är den bara för mottagning.
- **Återkopplingen (`autopilot/feedback/`) är inte ansluten** och har verifierats
  bara i simulering med en grov flygplansmodell. Alla siffror i
  `FeedbackConfig.h` som är märkta ”прикидка” (”grov uppskattning”) behöver förfinas på en verklig
  flygplansstomme; det finns ännu ingen lufthastighetssensor (utan den lärs roderytornas
  verkan in långsammare, och en överstegring syns bara genom
  inbromsningen).
- **Inte provat på hårdvara:** `ICM42688_Sensor` (anpassad till den gemensamma
  konventionen via `ImuSensorBase`), `BME280_Sensor` (Bosch-
  kompenseringen implementerades på nytt), BMP388 över SPI, `QMC5883L_Sensor`, GPS-
  inställningen via CFG-VALSET. Vid anslutning – startloggen, `s` i
  konsolen, tecken genom lutning.
- **I2C på ett kopplingsdäck fångar upp störningar** från ESC/motor (enstaka
  fel syns via `s`). Drivrutinerna överlever dem, men i flygplanet
  bör I2C-trådarna vara korta och hållas borta från kraftledningarna.
- **ESP32Servo används inte.** Version 3.2.1 på ESP32-S3 fördelar
  servona över MCPWM och förväxlar i `attachPin()` MCPWM-enhetens nummer med
  timerns nummer: GPIO6/7 gav signalen från GPIO4/5 (ESC:n
  styrdes av den högra spaken). Utgångarna skrevs om på LEDC; ta tillbaka
  biblioteket bara efter kontroll med `p`.
- **ESC:n är 50 Hz PWM**, firmwaren har ännu inget läge för kalibrering av
  gasområdet.
- **Webbpanel:** åtkomstpunktens lösenord är svagt, och kommandon
  tas emot även under flygning. Det är ett verktyg för bänken och fältet, inte för
  flygning.
- **Prototypens mekanik:** den första prototypen flög, ett svagt motorfäste och
  otillräcklig styvhet i vingen upptäcktes.
- **Licensen är OpenPlane License** ([LICENSE](LICENSE.md)): MIT med
  obligatorisk angivelse av upphovspersonen, förbud mot militär användning och förbud mot avsiktlig skada på människor och
  egendom utan deras skriftliga medgivande. Lägg inte till andra licenshuvuden
  i filerna och ta inte bort upphovspersonens namn.

---

## Hur man gör ändringar

- **Små commits:** ett logiskt steg – en commit.
- **Tester och analys före en commit:** `pio test -e native -e native-stm32`,
  `pio check -e esp32-s3`, `pio check -e stm32h743`, `tools/clang-tidy.sh` –
  allt grönt ([`TESTING.md`](TESTING.md)).
- **Bygg alla kort** efter ändringar i gemensam kod – STM32H743 är huvudkortet, men ESP32-S3, C3 och 38-pin får inte heller gå sönder; före en release – `tools/build_matrix.sh` (alla kort × alla sensorer).
- **Kontrollera på hårdvara det som kan kontrolleras:** tecken – genom lutning, utgångar – med
  kommandot `p`, förbindelsen – genom att stänga av sändaren.
- **Hitta inte på API:er.** Konsultera ramverkets källkod i
  `~/.platformio/packages/framework-arduinoespressif32/` (Arduino core 2.0.x)
  – internet beskriver ofta version 3.x med ett annat API (till exempel
  LEDC).
- **Försköna inte statusen.** Inte provat på hårdvara – säg det.
- **Ett lager får inte veta mer än det ska.** Om en lägre klass plötsligt
  behöver en högre måste logiken flyttas upp i `FlightController`.
- **När ett datakontrakt ändras** (`FlightOutputState`, `ControlCommand`,
  `ImuData`, JSON för `/api/status`) – uppdatera alla konsumenter i samma
  commit.

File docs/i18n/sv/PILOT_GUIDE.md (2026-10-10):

# Pilothandbok för OpenPlaneProject

> 🌐 Den här sidan är en översättning av [det ryska originalet](../../PILOT_GUIDE.md). Om översättningen och originalet skiljer sig åt gäller originalet. Firmwaren skriver ut sina konsolmeddelanden på ryska, så de citeras oförändrade. Översättningen är gjord av AI och har inte granskats av personer med svenska som modersmål. Rapportera fel till [Damir Lebedev](https://github.com/damir-lebedev) eller i [ärendehanteraren](https://github.com/damir-lebedev/OpenPlaneProject/issues).

Det här är en praktisk handbok om ”vad som kopplas vart och hur man flyger” för dem som håller i en lödkolv och en sändare snarare än läser källkod. Vill du förstå kodens arkitektur, se de andra dokumenten i repositoryt. Här handlar det bara om hårdvara, kanaler, firmware och flygning.

Repository: https://github.com/damir-lebedev/OpenPlaneProject, gren `main`.

Låt oss vara ärliga från början: projektet är under aktiv utveckling och är **ingen färdig produkt**. Den första prototypen har redan flugit, men med förbehåll som beskrivs i ett eget avsnitt längre ned. Läs det före flygningen, inte efter.

---

## Innehåll

1. [Vilken hårdvara du behöver](#vilken-hårdvara-du-behöver)
2. [Val av kort och stiftbeläggning](#val-av-kort-och-stiftbeläggning)
3. [Anslutning av mottagaren](#anslutning-av-mottagaren)
4. [RC-kanalkarta](#rc-kanalkarta)
5. [Autopilotkanaler](#autopilotkanaler)
6. [ARM och failsafe](#arm-och-failsafe)
7. [Flashning av kortet](#flashning-av-kortet)
8. [Webbpanel på fältet](#webbpanel-på-fältet)
9. [Svart låda](#svart-låda)
10. [Checklista före flygning och säkerhet](#checklista-före-flygning-och-säkerhet)
11. [Felsökning](#felsökning)
12. [Aktuellt läge för prototypens flygplansstomme](#aktuellt-läge-för-prototypens-flygplansstomme)

---

## Vilken hårdvara du behöver

Satsen i det nuvarande bygget (firmwaren har verifierats på den):

- **Ett STM32H743 DevEBox H743-kort** (MCUDEV) – huvudkortet. Det tidigare huvudkortet, ESP32-S3 nedan, stöds också.
- **Ett ESP32-S3 N16R8-kort** (en DevKitC-1-klon med två USB-C-portar: ”USB” och ”COM”).
- **En FS-i6-sändare + FS-iA6B-mottagare** (iBUS-protokoll, 10 kanaler). Du behöver en datatråd – iBUS SERVO-porten. Sändaren måste kunna ställa in failsafe – den inställningen är obligatorisk, se avsnittet om failsafe.
- **2 MG90S-servon** för skevrodren – ett för varje vinghalva (två oberoende servon, inte ett för båda vingarna).
- **1 MG90S-servo** för höjdrodret.
- **1 MG90S-servo** för sidrodret – landningsställets styrhjul sitter på samma axel (styrning på marken).
- **Ett elektroniskt fartreglage (ESC)** 60–80 A med en 5 V BEC (BEC:en driver servona och mottagaren).
- **En D3548 1100KV-motor** + **en 10x5-propeller**.
- **Ett 3S LiPo-batteri**.

Autopilotsensorer (alla på I2C; utan dem flyger planet i manuellt läge):

- **GY-521** – gyroskop + accelerometer (kortet kan ha en MPU6050 eller, som i vårt fall, en MPU6500 – båda stöds).
- **BMP581** – barometer (den tidigare BMP388 stöds också).
- **GY-273** – kompass (vår har en QMC5883P; QMC5883L stöds också).
- Valfritt en **OLED 128×64 SSD1306** (I2C) – en statusskärm ombord.

Flygplansstomme: spännvidd 1200 mm, korda 250 mm, profil NACA 4412, konstruktion i PETG (3D-utskriven). Den första prototypen flög med en ESP32-C3, en D2212 1000KV-motor och en 40 A ESC.

---

## Val av kort och stiftbeläggning

Firmwaren stöder fyra kort; bytet kräver en byggparameter (`pio run -e <miljöns namn>`). Varje kort har sin egen stiftbeläggning, hårdkodad i firmwaren för den specifika miljön – flytta inte om trådar på eget bevåg; titta i tabellen för ditt kort.

> **Viktigt:** huvudkortet är nu **STM32H743 (DevEBox H743)** – uppstart, USB-konsolen, SD-kortet, iBUS, servona och motorn har verifierats på det; sensorerna kopplas in för första gången. **esp32-s3 (N16R8)** är det tidigare huvudkortet; dess stiftbeläggning har verifierats på bänken med alla sensorer. **esp32-c3** är den gamla prototypen som har flugit. Stiftbeläggningen för **esp32-dev** valdes utifrån kretsens dokumentation och **har inte provats på riktig hårdvara**.

### STM32H743 (DevEBox H743) – huvudkortet

`pio run -e stm32h743-devebox`, ett MCUDEV DevEBox H743-kort (STM32H743VIT6). Det här är standardkortet (`default_envs = stm32h743-devebox`). Uppstart, USB-konsolen, SD-kortet och den svarta lådan, iBUS-mottagning, ARM, servon och motorn från sändaren har redan verifierats på det; sensorerna kopplas in för första gången.

| Syfte | Stift |
|---|---|
| Skevroder, vänster vinghalva | PA0 |
| Skevroder, höger vinghalva | PA1 |
| Höjdroder | PA2 |
| ESC (gas) | PA3 |
| Sidroder + styrhjul | PD14 |
| iBUS från mottagaren (RX) | PE7 |
| Sensorernas I2C SDA / SCL (MPU, BMP581, kompass) | PB11 / PB10 |
| OLED I2C SDA / SCL (separat buss) | PB9 / PB8 |
| GPS: RX (← GPS TX) / TX (→ GPS RX) | PD9 / PD8 |
| MAVLink-telemetri (radiomodem): RX / TX | PD0 / PD1 |
| AUX1 / AUX2 (servon), summer | PD15 / PE9, PE15 |
| Sensorernas SPI SCK / MISO / MOSI, IMU CS / barometer CS | PB13 / PB14 / PB15, PB12 / PD10 |
| Batteri / strömsensor (ADC, registreras av den svarta lådan) | PC0 / PC1 |

Konsolen, loggen och hämtningen från den svarta lådan går via kortets USB-C (en virtuell COM-port). Håll fria: PA11/PA12 (USB), PA13/PA14 (SWD), PC8–PC12 och PD2 (µSD-platsen), PE3 och PC5 (knapparna K1/K2).

Anslutning av sensorerna på bänken (alla moduler drivs med **3,3 V**, inte 5 V):

| Modul | Stift |
|---|---|
| MPU-6050 / GY-521 (kortet kan ha en MPU6500 – det går bra) | VCC–3.3V, GND–GND, SCL–PB10, SDA–PB11, AD0–GND, INT/XDA/XCL – lämna oanslutna. En fristående MPU-6500-modul (10 stift): samma sak, plus **NCS–3.3V** (annars går kretsen över till SPI) och FSYNC–GND; EDA/ECL – lämna oanslutna. Kretsen uppåt, X-pilen mot nosen; rotationen av kretsens axlar är `IMU_ROTATION_CW_DEG` i `Config.h` (90 på vår klon) |
| BMP581 | VCC–3.3V (**endast 3.3V**: många moduler har ingen egen regulator), GND–GND, SCL–PB10, SDA–PB11, **SDO–GND** (adress 0x46; lämna den inte flytande), **CSB–3.3V** (annars går kretsen över till SPI), INT – lämna oansluten |
| GY-273 (QMC5883P) | VCC–3.3V, GND–GND, SCL–PB10, SDA–PB11, DRDY – lämna oansluten. Håll den borta från servo-, ESC- och motortrådarna |
| OLED 128×64 SSD1306 | VCC–3.3V, GND–GND, SCL–PB8, SDA–PB9 |

Servona drivs **inte från kortet** utan från ESC:ns BEC (eller från en separat 5 V-källa på minst 2 A); alla källor har gemensam jord. Anslut inte ESC:ns röda tråd till kortets 5 V medan USB är inkopplad.

### esp32-s3 (N16R8) – det tidigare huvudkortet, verifierat på bänken

`pio run -e esp32-s3`, kort `esp32-s3-devkitc-1` med inställningar för N16R8-modulen (16 MB flash, 8 MB oktal PSRAM).

| Syfte | GPIO |
|---|---|
| Skevroder, vänster vinghalva | GPIO4 |
| Skevroder, höger vinghalva | GPIO5 |
| Höjdroder | GPIO6 |
| ESC (gas) | GPIO7 |
| Sidroder + styrhjul | GPIO18 |
| iBUS från mottagaren (RX) | GPIO17 |
| Sensorernas I2C SDA / SCL (MPU, BMP581, kompass) | GPIO41 / GPIO42 |
| OLED I2C SDA / SCL (separat buss) | GPIO1 / GPIO2 |
| Reserverat: GPS RX / TX | GPIO39 / GPIO40 |
| Reserverat: AUX1 / AUX2 (servon), AUX3, summer, LIGHT | GPIO15 / 16, 47, 38, 21 |
| Batteri / strömsensor (ADC, registreras av den svarta lådan); reserverat: telemetri TX / RX | GPIO8 / GPIO3, GPIO9 / GPIO10 |
| Endast bänk: SPI (ICM42688) SCK / MISO / MOSI / CS | GPIO12 / 13 / 11 / 14 (+ BMP388 CS – GPIO21) |

> Sensorbussen satt tidigare på GPIO8/9 – den flyttades till 41/42 för att stämma med flygkontrollerkortets layout.
> På bänken: SDA 8→41, SCL 9→42.

Använd inte: GPIO0/45/46 (startläget beror på dem), 19/20 (USB), 26–32 (flash), 33–37 (PSRAM på N16R8), 43/44 (”COM”-kontakten), 48 (RGB-lysdioden). De fria stiften är redan fördelade som reserver – ett bärarkort med kontakter för framtiden: [`FC_BOARD.md`](FC_BOARD.md).

Anslutning av sensorerna på bänken (alla moduler drivs med **3,3 V**, inte 5 V):

| Modul | Stift |
|---|---|
| MPU-6050 / GY-521 (kortet kan ha en MPU6500 – det går bra) | VCC–3.3V, GND–GND, SCL–GPIO42, SDA–GPIO41, AD0–GND, INT/XDA/XCL – lämna oanslutna. En fristående MPU-6500-modul (10 stift): samma sak, plus **NCS–3.3V** (annars går kretsen över till SPI) och FSYNC–GND; EDA/ECL – lämna oanslutna. Kretsen uppåt, X-pilen mot nosen; rotationen av kretsens axlar är `IMU_ROTATION_CW_DEG` i `Config.h` (90 på vår klon) |
| BMP581 | VCC–3.3V (**endast 3.3V**: många moduler har ingen egen regulator), GND–GND, SCL–GPIO42, SDA–GPIO41, **SDO–GND** (adress 0x46; lämna den inte flytande), **CSB–3.3V** (annars går kretsen över till SPI), INT – lämna oansluten |
| GY-273 (QMC5883P) | VCC–3.3V, GND–GND, SCL–GPIO42, SDA–GPIO41, DRDY – lämna oansluten. Håll den borta från servo-, ESC- och motortrådarna |
| OLED 128×64 SSD1306 | VCC–3.3V, GND–GND, SCL–GPIO2, SDA–GPIO1 |

Servona drivs **inte från kortet** utan från ESC:ns BEC (eller från en separat 5 V-källa på minst 2 A); alla källor har gemensam jord. Anslut inte ESC:ns röda tråd till kortets 5 V medan USB är inkopplad.

### esp32-c3 – den gamla prototypen, har flugit

`pio run -e esp32-c3`, kort `esp32-c3-devkitm-1`.

| Syfte | GPIO |
|---|---|
| Skevroder, vänster vinghalva | GPIO5 |
| Skevroder, höger vinghalva | GPIO4 |
| Höjdroder | GPIO6 |
| ESC (gas) | GPIO7 |
| Sidroder | – (inga lediga stift) |
| iBUS från mottagaren (RX) | GPIO8 |
| I2C SDA (sensorer) | GPIO1 |
| I2C SCL (sensorer) | GPIO3 |

### esp32-dev (den vanliga klassiska ESP32, 38 stift) – för bänken och felsökning, HAR INTE FLUGIT

`pio run -e esp32-dev`, kort `esp32dev`.

| Syfte | GPIO |
|---|---|
| Skevroder, vänster vinghalva | GPIO13 |
| Skevroder, höger vinghalva | GPIO14 |
| Höjdroder | GPIO27 |
| ESC (gas) | GPIO26 |
| Sidroder | GPIO25 |
| iBUS från mottagaren (RX) | GPIO16 |
| I2C SDA (sensorer) | GPIO21 |
| I2C SCL (sensorer) | GPIO22 |

Fördelen är att det är det vanligaste och billigaste kortet i familjen – lämpligt för felsökning av firmwaren på bänken, men dess stiftbeläggning har inte provats på hårdvara.

---

## Anslutning av mottagaren

Allt du behöver från mottagaren är **en iBUS-datatråd**, som på de flesta FlySky-kompatibla mottagare är utdragen till en separat port (ofta märkt ”iBUS”, eller så är det den enda utgången som inte är PPM). Anslutning:

- **Mottagarens TX (iBUS-utgång)** → kortets **RX-stift** från tabellen ovan (GPIO8 på esp32-c3, GPIO17 på esp32-s3, GPIO16 på esp32-dev).
- **Mottagarens jord (GND)** → kortets **GND**. Det är obligatoriskt; utan gemensam jord fungerar inte protokollet.
- **Mottagarens strömförsörjning** – från en separat BEC/regulator eller från kortets 5 V, beroende på hur du brukar driva mottagaren i dina byggen; den är inte knuten till något särskilt stift i firmwaren.

Firmwaren skickar ingenting tillbaka till mottagaren – den bara lyssnar, så kortets TX-ledning behöver inte anslutas någonstans.

iBUS-portens hastighet i firmwaren är 115200 baud, vilket är standard för protokollet; det finns ingen anledning att ändra den, eftersom mottagaren själv håller den hastigheten.

---

## RC-kanalkarta

Kartan verifierades på bänken med en FS-i6-sändare (10 kanaler, mode 2) och en FS-iA6B-mottagare.

| Kanal | Reglage på sändaren | Namn | Vad den gör |
|---|---|---|---|
| CH1 | höger spak ←→ | AILERON | Roll – skevroder (2000 = höger) |
| CH2 | höger spak ↑↓ | ELEVATOR | Tippning – höjdroder (2000 = spaken framåt, nosen ned) |
| CH3 | vänster spak ↑↓ | THROTTLE | Gas. 1000 µs = av, 2000 µs = max, ingen begränsning |
| CH4 | vänster spak ←→ | RUDDER | Sidroder och landningsställets styrhjul (ett servo) |
| CH5 | SwA | ARM | ARM-brytaren – se avsnittet om ARM nedan |
| CH6 | SwB | SWB | Klaffar som standard: ned, mot dig – utfällda, upp – infällda (se nedan) |
| CH7 | SwC (3 lägen) | SWC | Läge som standard: upp MANUAL, mitten STABILIZE, ned AUTO_TAKEOFF |
| CH8 | SwD | SWD | RTH (hem) som standard, så länge den är påslagen |
| CH9 | VrA | VRA | Stabiliseringens styrka som standard |
| CH10 | VrB | VRB | Marschfart som standard |

CH6–CH10 kan vara **vad som helst, på en rad** i `include/config/Controls.h`: vilket som helst av de 12 lägena, 10 funktionerna (klaffar, broms, lastsläpp, geofence, summer…) och 7 rattarna. När kortet startar skrivs den faktiska fördelningen ut i seriemonitorn. Allt om lägen och bindningar finns i [AUTOPILOT_GUIDE.md](AUTOPILOT_GUIDE.md).

Alla kanalvärden använder mottagarens standardpulsområde 1000–2000 µs, med 1500 µs som mitt/neutralläge.

### Klaffar (flaperoner)

Det finns inga separata klaffar – skevrodren fyller deras funktion. **SwB ned** (mot dig): båda skevrodren sänks mjukt, på ungefär en sekund, med samma vinkel (`FLAPS_DEPLOYED_US` = 220 µs ≈ 20° rotation av servoarmen – ändras i `include/config/Config.h`). Det ökar lyftkraften för start och landning i lägre fart. Roll från spaken och från autopiloten fungerar som vanligt – skevrodren rör sig åt motsatta håll, men nu runt det sänkta läget. **SwB upp** – de fälls in lika mjukt. På OLED-skärmen tänds `FL` på första raden medan klaffarna är utfällda.

Vid full roll med utfällda klaffar når det skevroder som rör sig nedåt sitt ändläge före det som rör sig uppåt – det är normalt och fungerar som skevroderdifferential.

Att fälla ut klaffarna lyfter oftast nosen – var beredd att trycka spaken lite framåt; om effekten är stark, justera genom att minska `FLAPS_DEPLOYED_US`.

---

## Autopilotkanaler

Kort sagt – standardfördelningen (`include/config/Controls.h`):

| Brytare | Vad den gör |
|---|---|
| **SwC** (CH7) | upp **MANUAL** · mitten **STABILIZE** · ned **AUTO_TAKEOFF** |
| **SwD** (CH8) | **RTH** – hem, så länge den är påslagen |
| **SwB** (CH6) | klaffar |
| **VrA / VrB** (CH9/10) | stabiliseringens styrka / marschfart |

- **STABILIZE – ”spaken anger vinkeln”.** Fullt spakutslag är 45° roll och 25° tippning; släpp spaken och flygplanet rätar upp sig självt. Gasen är din.
- **AUTO_TAKEOFF.** Efter ARM händer ingenting förrän du själv höjer gasen över hälften. Sedan: 0–1 s – gasen mjukt upp till 100 %, vingarna plana; 1–3 s – tippning +15°; därefter +10° tills du slår om SwC. Gas = det högsta av spaken och programmet.
- **RTH.** Kurs mot ARM-punkten, höjd 40 m, cirklar över hempunkten. Kräver GPS med 3D-fix **före ARM**.

Alla 12 lägen (ALT_HOLD, ACRO, CRUISE, LOITER, hand-LAUNCH, AUTO_LAND, SOARING, RESCUE…), vilka sensorer vart och ett kräver och hur det läggs på en brytare finns i [AUTOPILOT_GUIDE.md](AUTOPILOT_GUIDE.md). Ett läge som valts från panelen eller markstationen gäller tills du slår om lägesbrytaren.

Stabiliseringen rör roderytorna även när planet **inte är armerat** – så kan du på bänken se åt vilket håll det reagerar på en lutning. Integratorn ackumulerar inte i det fallet.

Vinkeltecken (som på OLED-skärmen och i loggen): **roll R > 0 – höger vinge ned, tippning P > 0 – nosen upp.**

---

## ARM och failsafe

### ARM-procedur

- **ARM:** gasen (CH3) i botten → brytaren **SwA (CH5) ned, mot dig** (på FS-i6 är det CH5 = 2000; upp = 1000). `ArmingManager: ARM` visas i Serial och `ARMED` på OLED-skärmen.
- **DISARM:** SwA upp, bort från dig – omedelbart, när som helst; motorn stannar direkt.
- Om SwA förs till ARM med gasen inte i botten, eller om kontrollerna före flygning inte har gått igenom, sker **ingen** ARM (orsaken skrivs ut i Serial). Du måste föra tillbaka SwA uppåt, sänka gasen och föra den nedåt igen.
- Om kortet startades med SwA redan i ARM-läget (ned) armeras det **inte**: firmwaren måste först se SwA uppe (OFF).

**ARM blockerar verkligen gasen:** så länge planet inte är armerat hålls ESC:ns gas tvångsmässigt på minimum oavsett spak. Före armering kontrollerar firmwaren att de sensorer som det valda läget kräver svarar – till exempel armeras inte STABILIZE utan en levande IMU förrän du byter till MANUAL. Bete dig ändå som om propellern kan börja snurra när som helst efter ARM.

### Failsafe

Förlorad förbindelse har **absolut prioritet** över allt annat:

- **planet är armerat, GPS och hempunkt finns** – **hemflygning med motor** (som i ArduPilot/INAV): kurs mot hempunkten, höjd 40 m, cirklar över hempunkten tills förbindelsen återkommer. OLED-skärmen visar `FSRTH`. Stängs av med `FAILSAFE_RTH = false` i `Config.h`;
- **planet är armerat, ingen GPS** – **glidflykt**: motorn är av, autopiloten håller i vilket läge som helst, även MANUAL, vingarna plana och nosen något under horisonten (−3°), och klaffarna fälls in. OLED-skärmen visar `RX LOST ... GLIDE`. Om du sätter `FAILSAFE_GLIDE_ROLL_DEG` = 10–20 kommer flygplanet att cirkla ovanför dig i en flack spiral;
- **inte armerat** (på marken) eller IMU:n svarar inte – motorn är av, skevrodren, höjdrodret och sidrodret går till neutralläge (1500 µs); efter 10 s utan förbindelse piper ”jag är här”-summern (om den är monterad).

Firmwaren känner igen förlorad förbindelse på två sätt:

1. **Inga iBUS-ramar på mer än 500 ms** – en bruten tråd eller en mottagare utan ström.
2. **Gas under 950 µs** – det är så mottagaren rapporterar att den har tappat sändaren. **Det kräver att failsafe ställs in i sändaren** (se nedan): när förbindelsen bryts slutar FS-iA6B INTE skicka ramar utan upprepar de senaste spakvärdena – utan inställningen ser firmwaren inte att förbindelsen är bruten, och flygplanet fortsätter flyga med den senaste gasen.

ARM återställs **inte** vid failsafe: när förbindelsen återkommer lyder flygplanet åter spakarna och det valda läget utan ny armering (att slå om brytaren i luften med gasen på noll är farligare).

Kontroll på bänken (propellern borttagen): ARM → stäng av sändaren → OLED-skärmen visar `RX LOST ... GLIDE`, motorn har stannat; luta flygplanet – roderytorna ska föra tillbaka det till plant läge. Slå på sändaren – `RX ok`, och styrningen är tillbaka hos spakarna.

### Inställning av failsafe i FS-i6-sändaren (obligatoriskt, en gång)

Idén: när förbindelsen bryts ska mottagaren ge en gas på ~900 µs – under det normala minimumet 1000.

1. `Menu → Functions setup → End points` → kanal 3: sätt den nedre punkten (det vänstra värdet) till **120 %**. Spara (långt tryck på Cancel).
2. Gas – **helt i botten**.
3. `Menu → Functions setup → Failsafe` → Channel 3 → **On**, gasen fortfarande i botten → spara med ett långt tryck på Cancel. Mottagaren kommer ihåg ~900 µs.
4. Gå tillbaka till `End points` → kanal 3 → sätt tillbaka den nedre punkten till **100 %**. Spara.
5. Kontroll: ARM behövs inte. Stäng av sändaren – efter ungefär 1 s visas `RX=LOST(failsafe пульта)` i Serial och en inverterad rad `RX LOST` på OLED-skärmen. Slå på sändaren – `RX=OK`.

Håll gastrimmet i mitten: med trimmet långt nedsänkt kan gasen hamna under 950 och firmwaren tar det för förlorad förbindelse.

Här fanns tidigare en **boost på CH8** och en gasbegränsning på 40 % – de har tagits bort: begränsningen skyddade ett svagt 3S1P-bygge, och nya batterier är inte rädda för full gas. Boosten brukade också slå på sig själv om SwD var uppe när kortet startades.

---

## Flashning av kortet

Firmwaren byggs med **PlatformIO** (Arduino-ramverket, C++).

### Installation av PlatformIO

Det enklaste är att installera tillägget **PlatformIO IDE** i VS Code (Extensions → sök ”PlatformIO IDE” → Install); då får du både CLI:t och praktiska byggknappar i gränssnittet. Du kan också installera det med `pip install platformio` och arbeta från terminalen – båda alternativen använder samma `pio`-kommandon.

### Bygga och ladda upp

Öppna projektet (repositoryts mapp) i VS Code med PlatformIO installerat, anslut kortet via USB och kör kommandot för ditt kort i terminalen:

```bash
# STM32H743 DevEBox (huvudkort)
pio run -e stm32h743-devebox -t upload

# esp32-s3 N16R8 (tidigare huvudkort)
pio run -e esp32-s3 -t upload

# esp32-c3 (gammal prototyp)
pio run -e esp32-c3 -t upload

# esp32-dev (klassisk ESP32 38-pin, för bänken)
pio run -e esp32-dev -t upload
```

Om du inte anger `-e` alls byggs standardkortet – `stm32h743-devebox`.

**STM32 DevEBox:** den första flashningen går via USB DFU: en bygel BT0→3V3, tryck på RST, sedan kommandot ovan (Windows behöver WinUSB-drivrutinen för ”STM32 BOOTLOADER”, installerad med Zadig). Därefter startar tangenten `D` i konsolen om kortet i bootloadern av sig självt, och bygeln behövs inte längre. Konsolen går via samma USB-C.

**esp32-s3:** kortet har två USB-C-kontakter. Flashning och Serial går via **”COM”**-kontakten (en CH343-brygga; i Windows visas den som ”USB-Enhanced-SERIAL CH343”). ”USB”-kontakten (kretsens inbyggda USB) behövs inte för driften, men den får vara ansluten – den stör ingenting.

### Seriemonitor

För att se felsökningsutskrifterna (kanalernas tillstånd, ARM, sensorer) direkt i konsolen via USB:

```bash
pio device monitor -b 115200
```

Hastigheten måste vara 115200 – annars ser du oläsligt skräp i stället för text. Var tionde sekund skrivs en `SYS`-rad ut – slingans frekvens (den ska vara ~500 Hz), den genomsnittliga och sämsta slingtiden under 10 s, iBUS-räknarna, ledigt minne. Allt annat kommer via de kanaler som är påslagna i loggmenyn (se nedan).

### Konsol: meny och logg (seriemonitor)

Ett tangenttryck verkar direkt; Enter behövs inte (i en monitor som skickar radvis, skriv bokstaven + Enter). Kalibreringar och kontrollen av utgångar fungerar bara när planet inte är armerat.

| Tangent | Vad den gör |
|---|---|
| `h` | **huvudmeny** (textbaserad, punkterna är numrerade) |
| `l` | menyn ”vad som ska skrivas till loggen” |
| mellanslag | pausa loggen / återuppta |
| `s` | detaljerad status för alla sensorer (inklusive I2C-felräknarna) |
| `i` | kalibrera om gyroskopet och kör IMU-kontrollen före flygning – 2 s, rör inte flygplanet |
| `o` | **kalibrering av IMU-monteringen** – en gång, efter att kortet monterats i flygplanet (se nedan) |
| `m` | kompasskalibrering – rotera kortet/flygplanet runt alla axlar i 15 s. Resultatet sparas i flash och överlever en omstart |
| `p` | kontroll av utgångar: den faktiska pulsen på varje stift |

**Loggning per kanal.** Varje typ av data är en egen rad med eget prefix, och var och en har sitt eget läge: **av**, **vid ändring** (en rad visas bara när värdena verkligen har ändrats – spakdarrning och sensorbrus räknas inte) eller **kontinuerligt** (var 0,2 / 0,5 / 1 / 2 s – perioden ställs in i samma meny).

| Kanal | Vad den visar | Standard |
|---|---|---|
| `STAT` | förbindelse, ARM, läge, klaffar, om IMU/barometer är OK | vid ändring |
| `RC` | sändarkanaler, µs | av |
| `OUT` | utgångar till roderytorna och ESC:n, µs | av |
| `ATT` | roll, tippning, kurs | av |
| `AP` | autopilot: mål och korrigeringar | av |
| `ALT` | höjd, vertikal hastighet, ALT_HOLD-mål | av |
| `MAG` | kompasskurs | av |
| `GPS` | fix, satelliter, koordinater, hastighet | av |
| `IMU` | gyroskop och accelerometer | av |
| `SYS` | slingans frekvens och tid, minne (var 10:e s) | på |

Medan menyn är öppen är loggen tyst så att menyn inte rullar bort; när du lämnar den skrivs alla påslagna kanaler ut igen. Valet sparas i flash när du lämnar menyn och överlever en omstart. När planet är armerat verkar det direkt men skrivs först efter DISARM: en skrivning till flash stoppar flygslingan i ~0,4 s.

### IMU-montering: hur du vill, en kalibrering

Kortet med IMU:n kan monteras i flygplanet **hur det passar** – i vilken vinkel som helst, på sidan, upp och ned: firmwaren räknar själv ut var dess nos och ovansida är. Det görs **en gång** efter monteringen (och igen om kortet har flyttats):

1. Flygplanet på bordet, ingen sändare behövs, motorn inte armerad. Tryck `o` i seriemonitorn.
2. **Steg 1:** flygplanet står plant, som i planflykt (för ett flygplan med sporrhjul, lägg något under stjärten). Rör det inte i ~3 s.
3. **Steg 2:** höj **nosen** 30–60°, vingarna plana, och håll stilla i ~1 s.
4. **Steg 3:** nosen tillbaka ned, sänk den **högra vingen** 30–60° och håll i ~1 s.

Varje steg räknas av sig självt (loggen skriver ”засчитано”, det vill säga ”godkänt”). I slutet visas vad som kom fram (”нос = +Y чипа, верх = −Z чипа”, det vill säga ”nos = kretsens +Y, upp = kretsens −Z”) och ”установка сохранена” (”monteringen sparad”). Om du har blandat ihop något (sänkt nosen i stället för att höja den, vänster vinge i stället för höger) avvisas kalibreringen med en förklaring; upprepa bara `o`. Resultatet lagras i flash och överlever en omstart. Kontroll: nosen upp → P på OLED-skärmen blir positivt; höger vinge ned → R blir positivt.

Så länge ingen monteringskalibrering finns gäller den gamla metoden: kortet måste ligga med kretsen uppåt, och rotationen är `IMU_ROTATION_CW_DEG` i `Config.h`.

### Kontroll före flygning vid start

Vid varje start ägnar IMU:n ~2 s åt att kalibrera gyroskopet och kontrollerar samtidigt sig själv:

- **flygplanet står stilla** – om det hölls i händerna eller flyttades i det ögonblicket blir gyroskopets offset fel;
- accelerometern i vila visar 1g;
- **”upp” stämmer med monteringskalibreringen** – om kortet har flyttats eller vänts syns det direkt (ett flygplan på sporrhjulet eller i en sluttning är inget problem; toleransen är 45°).

**Slå på flygplanet medan det står stilla.** Det behöver inte stå plant om monteringen är kalibrerad (annars blir läget vid start horisonten). Resultatet syns i loggen: `предполётная проверка пройдена` (”kontrollen före flygning godkänd”) eller `ПРЕДПОЛЁТНАЯ ПРОВЕРКА НЕ ПРОЙДЕНА — <причина>` (”KONTROLLEN FÖRE FLYGNING EJ GODKÄND” följt av orsaken). Om den misslyckades är **ARM i STABILIZE och AUTO_TAKEOFF förbjuden** (orsaken skrivs ut när du försöker), och autopiloten ger inga korrigeringar i något läge, inklusive glidflykt vid förlorad förbindelse: med fel vinklar skulle den styra åt fel håll. ARM i MANUAL är fortfarande möjlig. Så åtgärdar du det: ställ ned flygplanet orörligt och anslut batteriet på nytt (eller tryck `i`); om kortet har flyttats, tryck `o`.

### OLED-skärm

Om OLED-skärmen är ansluten (GPIO1/GPIO2) visar den följande 5 gånger per sekund:

```
RX ok disarm STAB        <- förbindelse / ARM / läge (vid förlorad förbindelse inverteras raden)
R  +1.2 P  -0.4          <- roll / tippning, °
Alt +0.3 Vz +0.1         <- höjd från startpunkten, m / vertikal hastighet, m/s
Hdg 123  Thr 1000        <- kompasskurs / gas till ESC:n, µs
L1500 R1500 E1500        <- PWM för skevrodren och höjdrodret, µs
Loop 500Hz max 1100us    <- frekvens och sämsta slingtid
```

---

## Webbpanel på fältet

Kortet startar en egen Wi-Fi-åtkomstpunkt – ingen router hemma eller internet behövs, och allt fungerar direkt på fältet från en telefon.

**Så ansluter du:**

1. Öppna listan över Wi-Fi-nätverk på en telefon eller bärbar dator.
2. Anslut till nätverket **`OpenPlane-Debug`**, lösenord **`12345678`**.
3. Öppna adressen **`http://192.168.4.1`** i en webbläsare.

Ingen app behöver installeras – det är en vanlig webbsida.

**Vad du kan göra från en telefon på fältet, helt utan programmering:**

- Se **levande staplar för alla 10 RC-kanaler** – praktiskt för att kontrollera att sändaren och mottagaren verkligen skickar det du rör på spaken, redan innan servona ansluts.
- Se status för varje utgång (vänster/höger skevroder, höjdroder, ESC) – om kanalen är ansluten i mjukvaran.
- Se om sensorerna (IMU, barometer) svarar, om du har dem monterade – den visar ärligt antingen riktiga data (roll/tippning/höjd) eller en tydlig notering om att sensorn fysiskt saknas eller inte svarar.
- **Byta autopilotläge** med knappar (manuellt / stabilisering / autostart / höjdhållning) direkt från sidan – utan sändaren.
- **Justera PID-regulatorns koefficienter** (för roll och tippning) via ett formulär på sidan – användbart för att stegvis trimma stabiliseringen utan att flasha om.

Räckvidden för den här åtkomstpunkten är i praktiken tiotals meter; det är vanlig ESP32-Wi-Fi, inte telemetri med lång räckvidd. Det är ett verktyg för justering på bordet, på bänken och bredvid fältet – inte för att styra planet under flygning på avstånd.

---

## Svart låda

ESP32-S3-firmwaren registrerar själv varje flygning i flash: allt som sensorerna såg, vad spakarna gjorde, vart servona gick och vad autopiloten bestämde. Det finns inget att göra:

- den **spelar in** från det ögonblick planet armeras och gasen höjs (plus 10 s dessförinnan);
- den **stannar** 10 s efter DISARM – eller om ett armerat plan står orörligt med motorn av i 30 s (det landade eller kraschade, och DISARM glömdes);
- förlorad förbindelse, motor på noll och glidflykt stoppar **inte** inspelningen.

Vid start visar seriemonitorn hur mycket utrymme det finns för en flygning (konsolen skriver på ryska; raden nedan betyder ”väntar på ARM och gas | raderat i förväg 12.9 MB (≈11 min) av 13.9 MB | flygningar 1”):

```
BlackBox: ждёт ARM и газ | стёрто впереди 12.9 МБ (≈11 мин) из 13.9 МБ | полётов 1
```

**Efter flygningen**, anslut USB (COM-kontakten), stäng seriemonitorn och hämta flygningen:

```bash
python tools/blackbox.py download
```

Flygningen hamnar i mappen `blackbox/` tillsammans med den avkodade utdatan: `summary.txt` (sammanfattningen och händelserna), `events.txt` och CSV-tabeller per sensor. Den svarta lådan raderar själv gamla flygningar när den behöver utrymme – **hämta efter varje flygning**. Konsolmenyn är tangenten `k`. Alla detaljer finns i [BLACKBOX.md](BLACKBOX.md).

**På STM32H743-kortet** spelar den svarta lådan in på ett SD-kort: kortet formateras som FAT32 och förbereds en gång på en dator (`python tools/blackbox.py sd-prepare E:`). Efter en flygning kan den hämtas via USB med samma `download`-kommando, eller så tar du ut kortet och avkodar filen direkt från det: `python tools/blackbox.py ring E:/BLACKBOX.BIN`.

---

## Checklista före flygning och säkerhet

Läs det här avsnittet i sin helhet **före** den första starten, inte efter en incident.

### Obligatoriskt före varje bänktest

- [ ] **Propellern är fysiskt BORTTAGEN** om du kontrollerar kanaler, ARM, panelen, justerar PID eller bara startar kortet för första gången med en ny stiftbeläggning. ESC:n kan rycka i motorn i vilket skede av ett test som helst – det är ingen hypotetisk risk utan normalt beteende vid första start.
- [ ] LiPo-batteriet har kontrollerats för svullnad och skador, laddats med en riktig LiPo-laddare och förvaras och laddas på ett obrännbart underlag.
- [ ] Sändaren är påslagen och dess kanaler har kontrollerats på panelen (`http://192.168.4.1`) **innan** batteriet ansluts till ESC:n.

### Före flygning

- [ ] Ett öppet område, utan människor eller byggnader inom en radie som räcker för ett flygplan med 1200 mm spännvidd under manuell styrning med onormalt beteende hos servona eller vingen (se avsnittet om prototypens begränsningar nedan – motorfästet och vingen har ännu inte förstärkts med kolfiber).
- [ ] Alla tre ytorna rör sig åt rätt håll – kontrollera på bordet före varje flygning och lita inte på minnet från förra gången:
  - höger spak åt höger → **höger skevroder upp, vänster skevroder ned**;
  - höger spak mot dig → **höjdrodret upp**;
  - vänster spak åt höger → **sidroder och hjul åt höger**;
  - SwB (klaffar) ned → **båda skevrodren mjukt ned**, och roll från spaken rör dem fortfarande åt motsatta håll;
  - i STABILIZE, luta flygplanet med höger vinge ned → **höger skevroder ned, vänster skevroder upp** (ytorna för tillbaka det till plant läge); nosen ned → **höjdrodret upp**.
  Om något är fel, ändra motsvarande `*_REVERSED` i `include/config/Config.h` (avsnittet ”Servo direction”), inte reverseringen på sändaren: annars blir spaken och autopiloten oense.
- [ ] Vid start stod flygplanet stilla, och loggen eller panelen visar inte `ПРЕДПОЛЁТНАЯ ПРОВЕРКА НЕ ПРОЙДЕНА`; när du lutar flygplanet i händerna ändras P och R på OLED-skärmen åt rätt håll.
- [ ] Failsafe är inställt i sändaren och provat: stäng av sändaren → `RX LOST` på OLED-skärmen/i Serial (se avsnittet om failsafe).
- [ ] Sändarens räckvidd har kontrollerats, och sändarens batteri är laddat.
- [ ] Vid start visar loggen `BlackBox: ... стёрто впереди N МБ (≈M мин)` – det finns tillräckligt med utrymme för flygningen. Den föregående flygningen har hämtats (`python tools/blackbox.py download`), om du behöver den.
- [ ] Håll händer och ansikte borta från propellern så snart en LiPo är ansluten till ESC:n – efter ARM reagerar gasen på spaken direkt, utan fler varningar. DISARM – SwA upp.
- [ ] Se till att du fysiskt kan koppla bort strömmen snabbt (åtkomst till LiPo-kontakten) i stället för att bara förlita dig på failsafe vid signalförlust.

### Allmän LiPo-säkerhet

- Lämna aldrig en LiPo som laddas utan uppsikt.
- Anslut eller koppla inte bort LiPo:n från ESC:n medan du står i propellerns rotationsplan.
- Transportera och förvara LiPo-batterier i en skyddspåse eller låda.

---

## Felsökning

**”Ingen mottagarsignal” / RX ser bra ut, men kanalerna på panelen rör sig inte**
Kontrollera att mottagarens datatråd är ansluten exakt till iBUS RX-stiftet från ditt korts tabell (GPIO8/GPIO17/GPIO16), inte förväxlad med jord eller ström, och att mottagarens och kortets jord är sammankopplade. Om stiftbeläggningen stämmer och trådarna är hela men det fortfarande inte finns någon signal, kontrollera att mottagaren överhuvudtaget är bunden till sändaren och att mottagarens utgång är inställd på iBUS, inte PPM/SBUS.

**En sensor (IMU, barometer, kompass) visar ”svarar inte” / NO_RESPONSE**
Firmwaren rapporterar ärligt att sensorn inte svarar i stället för att mata ut nollor. Kontrollera: (1) modulens strömförsörjning – 3.3V och kortets jord; (2) SDA/SCL – på I2C-stiften för just ditt kort; (3) adressen på ledningen: MPU 0x68 (AD0 till GND), BMP581 0x46 (SDO till GND, CSB till 3.3V; 0x47 om SDO ligger på 3.3V), BMP388 0x76 (SDO till GND, **CSB till 3.3V** – annars är kretsen i SPI-läge), QMC5883P 0x2C, QMC5883L 0x0D. Om en sensor ibland svarar och ibland inte (eller svarar på någon annans adress) är det dålig kontakt på kopplingsdäcket: tryck till VCC/GND/SDA/SCL, och helst bör varje modul matas direkt från kortets 3.3V/GND. Kommandot `s` i konsolen visar I2C-felräknarna för varje sensor.

**Vinklarna på OLED-skärmen är förväxlade (nosen upp ändrar R, inte P) eller har fel tecken**
Gör kalibreringen av IMU-monteringen (`o`, se ”IMU-montering”) – den beror inte på hur kretsen är lödd på modulen eller hur modulen sitter i flygplanet. Utan den: på GY-521-kloner är kretsen ibland lödd vriden i förhållande till de tryckta pilarna – rotera axlarna i `Config.h` → `IMU_ROTATION_CW_DEG` (0/90/180/270). Kontroll: nosen upp → P blir positivt, höger vinge ned → R blir positivt.

**ARM nekad: ”IMU: ...”**
IMU-kontrollen före flygning gick inte igenom (se ”Kontroll före flygning vid start”): flygplanet rördes vid start – ställ ned det orörligt och anslut batteriet på nytt; ”upp” stämmer inte med kalibreringen – kortet har flyttats, gör `o`; ”kortet ligger inte med kretsen uppåt” – monteringen är inte kalibrerad, gör `o`.

**Ett servo eller ESC:n reagerar på fel spak / reagerar inte**
Kommandot `p` i konsolen mäter den verkliga pulsen på varje utgång (GPIO4–7) och jämför den med den förväntade. Om allt är ”OK” men servot inte rör sig ligger problemet utanför kortet: (1) servot får ingen ström (BEC/5V, gemensam jord); (2) signaltråden sitter på fel stift; (3) mekanismen har fastnat. ”НЕ СОВПАДАЕТ” (”STÄMMER INTE”) betyder att problemet finns i firmwaren eller kringutrustningen – rapportera det till utvecklaren.

**Motorn snurrar inte alls, fast gasen på OLED-skärmen/panelen följer spaken**
Kontrollera att LiPo:n är ansluten till ESC:n och att planet verkligen är armerat – före ARM hålls gasen till ESC:n tvångsmässigt på minimum, och det är inget fel. En ESC som såg en gas som inte var minimum vid start kan pipa hela tiden och vägra armera – anslut batteriet på nytt med gasen i botten. Om `ArmingManager: ARM` inte visas efter att SwA förts ned, titta i Serial – firmwaren skriver ut orsaken (gasen är inte i botten, en sensor svarar inte, en som behövs för det läge som för närvarande är valt på CH7); för tillbaka SwA uppåt, åtgärda orsaken och för den nedåt igen.

**Motorn stannar eller rycker vid uppvarvning**
Om ESC:n drivs från ett labbaggregat slår du i aggregatets strömgräns: även utan propeller drar motorn kortvarigt flera ampere, spänningen sjunker och ESC:n startar om. Höj strömgränsen eller använd en LiPo. Spikar från en sådan omstart kan låsa kortets USB-brygga (”COM”-porten slutar gå att öppna) – anslut kabeln på nytt.

**Efter flashning svarar inte kortet / åtkomstpunkten `OpenPlane-Debug` visas inte**
Se till att uppladdningen (`pio run -e <ditt kort> -t upload`) avslutades utan fel och att du flashade exakt den miljö du fysiskt håller i handen (esp32-c3 skiljer sig från esp32-s3 och esp32-dev inte bara i stiften utan också i kretsen – firmware för en annan krets installeras inte på kortet, eller installeras felaktigt). Kontrollera seriemonitorns utskrift (`pio device monitor -b 115200`) direkt efter att kortet startat om – den visar i vilket skede av setup() kortet befinner sig.

---

## Aktuellt läge för prototypens flygplansstomme

För att hålla förväntningarna ärliga:

- Den första prototypen **har redan flugit**. Problem upptäcktes: **otillräcklig hållfasthet i motorfästet** och **otillräcklig hållfasthet i vingen** – vingen behöver förstärkas med kolfiber. Servona behöver också justeras ytterligare. Ta hänsyn till detta när du planerar egna flygningar – det är ingen abstrakt friskrivning utan ett verkligt haveri som redan har inträffat på den här prototypen.
- **esp32-s3-bänken är byggd med alla sensorer** (GY-521 med en MPU6500, en BMP388 på I2C, en GY-273 med en QMC5883P, en OLED) – alla svarar, och slingan går på 500 Hz. Autopilotlägena har verifierats på bordet men **har ännu inte provats under flygning**.
- Standardbarometern är nu BMP581 (bänkens BMP388 verifierades live; BMP581 har ännu inte provats på hårdvara). Höjden är relativ till startpunkten. Absolut höjd över havet räknas fram ur standardatmosfären, utan väderkorrigering.
- QMC5883P-kompassen behöver kalibreras (`m` i konsolen) på det monterade flygplanet – bredvid motorn och trådarna skiljer sig offseten från dem på kopplingsdäcket. Kursen har ännu ingen lutningskompensation och används inte av något läge.
- Licensen är OpenPlane License: MIT med obligatorisk angivelse av upphovspersonen (Damir Lebedev), förbud mot militär användning och förbud mot att avsiktligt skada människor eller egendom utan deras medgivande, se [LICENSE](LICENSE.md).

Om du bygger ditt eget plan efter den här handboken, flyg det först med manuell styrning (MANUAL) och gå först därefter vidare till autopiloten.

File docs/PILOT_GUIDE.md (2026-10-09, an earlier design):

# Гайд пилота OpenPlaneProject

Это практический гайд «что куда подключать и как летать» для тех, кто держит в руках паяльник и пульт, а не читает исходники. Если хочется разобраться в архитектуре кода — это в другие документы репозитория. Здесь — только железо, каналы, прошивка и полёты.

Репозиторий: https://github.com/damir-lebedev/OpenPlaneProject, ветка `main`.

Сразу честно: проект в активной разработке, это **не готовый продукт**. Первый прототип уже летал, но с оговорками, которые ниже расписаны отдельным разделом. Читайте его перед полётом, а не после.

---

## Содержание

1. [Что нужно из железа](#что-нужно-из-железа)
2. [Выбор платы и распиновка](#выбор-платы-и-распиновка)
3. [Подключение приёмника](#подключение-приёмника)
4. [Карта RC-каналов](#карта-rc-каналов)
5. [Каналы автопилота](#каналы-автопилота)
6. [ARM и failsafe](#arm-и-failsafe)
7. [Прошивка платы](#прошивка-платы)
8. [Веб-дашборд в поле](#веб-дашборд-в-поле)
9. [Чёрный ящик](#чёрный-ящик)
10. [Предполётный чек-лист и безопасность](#предполётный-чек-лист-и-безопасность)
11. [Troubleshooting](#troubleshooting)
12. [Текущее состояние прототипа-планера](#текущее-состояние-прототипа-планера)

---

## Что нужно из железа

Комплект текущей сборки (на нём проверена прошивка):

- **Плата STM32H743 DevEBox H743** (MCUDEV) — основная. Прежняя основная, ESP32-S3 ниже, тоже поддерживается.
- **Плата ESP32-S3 N16R8** (DevKitC-1-клон с двумя USB-C: "USB" и "COM").
- **Пульт FS-i6 + приёмник FS-iA6B** (протокол iBUS, 10 каналов). Нужен один провод данных — порт iBUS SERVO. Пульт должен уметь задавать failsafe — это обязательная настройка, см. раздел про failsafe.
- **2 сервопривода MG90S** на элероны — по одному на каждую консоль (два независимых серво, не один на оба крыла).
- **1 сервопривод MG90S** на лифт (руль высоты).
- **1 сервопривод MG90S** на руль направления — на его же ось посажено рулевое колесо шасси (руление на земле).
- **Регулятор оборотов (ESC)** 60–80A с BEC 5V (BEC питает сервы и приёмник).
- **Мотор D3548 1100KV** + **пропеллер 10x5**.
- **Аккумулятор LiPo 3S**.

Датчики автопилота (все по I2C, без них борт летает в ручном режиме):

- **GY-521** — гироскоп + акселерометр (на плате бывает MPU6050 или, как у нас, MPU6500 — оба поддерживаются).
- **BMP581** — барометр (прежний BMP388 тоже поддерживается).
- **GY-273** — компас (у нас на нём QMC5883P; QMC5883L тоже поддерживается).
- Опционально **OLED 128×64 SSD1306** (I2C) — экран статуса на борту.

Планер: размах крыла 1200 мм, хорда 250 мм, профиль NACA 4412, конструкция из PETG (3D-печать). Первый прототип летал на ESP32-C3, моторе D2212 1000KV и ESC 40A.

---

## Выбор платы и распиновка

Прошивка поддерживает четыре платы, переключение — один параметр при сборке (`pio run -e <имя окружения>`). Распиновка у каждой платы своя и жёстко прописана в прошивке под конкретное окружение — переставлять провода самовольно нельзя, нужно смотреть таблицу под свою плату.

> **Важно:** основная плата теперь **STM32H743 (DevEBox H743)** — на ней проверены загрузка, консоль по USB, SD-карта, iBUS, сервы и мотор; датчики подключаются впервые. **esp32-s3 (N16R8)** — прежняя основная, её распиновка проверена на стенде со всеми датчиками. **esp32-c3** — старый облётанный прототип. Распиновка **esp32-dev** подобрана по документации чипа и **не проверена на реальном железе**.

### STM32H743 (DevEBox H743) — основная плата

`pio run -e stm32h743-devebox`, плата MCUDEV DevEBox H743 (STM32H743VIT6). Это плата по умолчанию (`default_envs = stm32h743-devebox`). На ней уже проверены загрузка, консоль по USB, SD-карта и чёрный ящик, приём iBUS, ARM, сервы и мотор с пульта; датчики подключаются впервые.

| Назначение | Пин |
|---|---|
| Элерон, левая консоль | PA0 |
| Элерон, правая консоль | PA1 |
| Лифт (руль высоты) | PA2 |
| ESC (газ) | PA3 |
| Руль направления + рулевое колесо | PD14 |
| iBUS от приёмника (RX) | PE7 |
| I2C датчиков SDA / SCL (MPU, BMP581, компас) | PB11 / PB10 |
| I2C OLED SDA / SCL (отдельная шина) | PB9 / PB8 |
| GPS: RX (← TX GPS) / TX (→ RX GPS) | PD9 / PD8 |
| Телеметрия MAVLink (радиомодем): RX / TX | PD0 / PD1 |
| AUX1 / AUX2 (сервы), пищалка | PD15 / PE9, PE15 |
| SPI датчиков SCK / MISO / MOSI, CS IMU / CS барометра | PB13 / PB14 / PB15, PB12 / PD10 |
| Батарея / датчик тока (АЦП, пишет чёрный ящик) | PC0 / PC1 |

Консоль, лог и выгрузка чёрного ящика идут через USB-C платы (виртуальный COM-порт). Не занимать: PA11/PA12 (USB), PA13/PA14 (SWD), PC8–PC12 и PD2 (слот µSD), PE3 и PC5 (кнопки K1/K2).

Подключение датчиков на стенде (все модули — от **3.3V**, не от 5V):

| Модуль | Пины |
|---|---|
| MPU-6050 / GY-521 (на плате может стоять MPU6500 — это нормально) | VCC–3.3V, GND–GND, SCL–PB10, SDA–PB11, AD0–GND, INT/XDA/XCL — не подключать. Отдельный модуль MPU-6500 (10 ножек): то же, плюс **NCS–3.3V** (иначе чип уходит в SPI) и FSYNC–GND, EDA/ECL — не подключать. Плата чипом вверх, стрелка X — к носу; поворот осей чипа — `IMU_ROTATION_CW_DEG` в `Config.h` (у нашего клона 90) |
| BMP581 | VCC–3.3V (**только 3.3V**: у многих модулей нет своего стабилизатора), GND–GND, SCL–PB10, SDA–PB11, **SDO–GND** (адрес 0x46; в воздухе не оставлять), **CSB–3.3V** (иначе чип уходит в SPI), INT — не подключать |
| GY-273 (QMC5883P) | VCC–3.3V, GND–GND, SCL–PB10, SDA–PB11, DRDY — не подключать. Подальше от проводов серв/ESC/мотора |
| OLED 128×64 SSD1306 | VCC–3.3V, GND–GND, SCL–PB8, SDA–PB9 |

Сервы питаются **не от платы**, а от BEC регулятора (или отдельного 5V ≥2 А); земля всех источников общая. Красный провод ESC не подключать к 5V платы, пока воткнут USB.

### esp32-s3 (N16R8) — прежняя основная плата, проверена на стенде

`pio run -e esp32-s3`, плата `esp32-s3-devkitc-1` с настройками под модуль N16R8 (16 МБ флеша, 8 МБ octal PSRAM).

| Назначение | GPIO |
|---|---|
| Элерон, левая консоль | GPIO4 |
| Элерон, правая консоль | GPIO5 |
| Лифт (руль высоты) | GPIO6 |
| ESC (газ) | GPIO7 |
| Руль направления + рулевое колесо | GPIO18 |
| iBUS от приёмника (RX) | GPIO17 |
| I2C датчиков SDA / SCL (MPU, BMP581, компас) | GPIO41 / GPIO42 |
| I2C OLED SDA / SCL (отдельная шина) | GPIO1 / GPIO2 |
| Резерв: GPS RX / TX | GPIO39 / GPIO40 |
| Резерв: AUX1 / AUX2 (сервы), AUX3, пищалка, LIGHT | GPIO15 / 16, 47, 38, 21 |
| Батарея / датчик тока (АЦП, пишет чёрный ящик); резерв: телеметрия TX / RX | GPIO8 / GPIO3, GPIO9 / GPIO10 |
| Только стенд: SPI (ICM42688) SCK / MISO / MOSI / CS | GPIO12 / 13 / 11 / 14 (+ CS BMP388 — GPIO21) |

> Шина датчиков раньше была на GPIO8/9 — перенесена на 41/42 под разводку
> платы полётника. На стенде: SDA 8→41, SCL 9→42.

Не занимать: GPIO0/45/46 (от них зависит режим загрузки), 19/20 (USB), 26–32 (флеш), 33–37 (PSRAM у N16R8), 43/44 (разъём "COM"), 48 (RGB-светодиод). Свободные пины уже распределены под резерв — плата-носитель с разъёмами на будущее: [`FC_BOARD.md`](FC_BOARD.md).

Подключение датчиков на стенде (все модули — от **3.3V**, не от 5V):

| Модуль | Пины |
|---|---|
| MPU-6050 / GY-521 (на плате может стоять MPU6500 — это нормально) | VCC–3.3V, GND–GND, SCL–GPIO42, SDA–GPIO41, AD0–GND, INT/XDA/XCL — не подключать. Отдельный модуль MPU-6500 (10 ножек): то же, плюс **NCS–3.3V** (иначе чип уходит в SPI) и FSYNC–GND, EDA/ECL — не подключать. Плата чипом вверх, стрелка X — к носу; поворот осей чипа — `IMU_ROTATION_CW_DEG` в `Config.h` (у нашего клона 90) |
| BMP581 | VCC–3.3V (**только 3.3V**: у многих модулей нет своего стабилизатора), GND–GND, SCL–GPIO42, SDA–GPIO41, **SDO–GND** (адрес 0x46; в воздухе не оставлять), **CSB–3.3V** (иначе чип уходит в SPI), INT — не подключать |
| GY-273 (QMC5883P) | VCC–3.3V, GND–GND, SCL–GPIO42, SDA–GPIO41, DRDY — не подключать. Подальше от проводов серв/ESC/мотора |
| OLED 128×64 SSD1306 | VCC–3.3V, GND–GND, SCL–GPIO2, SDA–GPIO1 |

Сервы питаются **не от платы**, а от BEC регулятора (или отдельного 5V ≥2 А); земля всех источников общая. Красный провод ESC не подключать к 5V платы, пока воткнут USB.

### esp32-c3 — старый прототип, облётан

`pio run -e esp32-c3`, плата `esp32-c3-devkitm-1`.

| Назначение | GPIO |
|---|---|
| Элерон, левая консоль | GPIO5 |
| Элерон, правая консоль | GPIO4 |
| Лифт (руль высоты) | GPIO6 |
| ESC (газ) | GPIO7 |
| Руль направления | — (свободных пинов нет) |
| iBUS от приёмника (RX) | GPIO8 |
| I2C SDA (датчики) | GPIO1 |
| I2C SCL (датчики) | GPIO3 |

### esp32-dev (обычная классическая ESP32, 38 пинов) — для стенда/отладки, НЕ ОБЛЁТАНА

`pio run -e esp32-dev`, плата `esp32dev`.

| Назначение | GPIO |
|---|---|
| Элерон, левая консоль | GPIO13 |
| Элерон, правая консоль | GPIO14 |
| Лифт (руль высоты) | GPIO27 |
| ESC (газ) | GPIO26 |
| Руль направления | GPIO25 |
| iBUS от приёмника (RX) | GPIO16 |
| I2C SDA (датчики) | GPIO21 |
| I2C SCL (датчики) | GPIO22 |

Удобна тем, что это самая распространённая и дешёвая плата линейки — подходит для стендовой отладки прошивки, но распиновка не проверена на железе.

---

## Подключение приёмника

Всё, что нужно от приёмника — это **один провод данных iBUS**, который на большинстве FlySky-совместимых приёмников выведен на отдельный порт (часто подписан "iBUS" или это единственный не-PPM выход). Подключение:

- **Приёмник TX (выход iBUS)** → **RX-пин платы** из таблицы выше (GPIO8 на esp32-c3, GPIO17 на esp32-s3, GPIO16 на esp32-dev).
- **Земля (GND) приёмника** → **GND платы**. Обязательно, без общей земли протокол работать не будет.
- **Питание приёмника** — от отдельного BEC/регулятора или от 5V платы, в зависимости от того, чем вы обычно питаете приёмник в своих сборках; это не завязано на конкретный пин прошивки.

Прошивка не отправляет ничего обратно приёмнику — она только слушает, поэтому линию TX платы никуда подключать не нужно.

Скорость порта iBUS в прошивке — 115200 бод, это стандарт для протокола, менять не нужно, приёмник сам держит эту скорость.

---

## Карта RC-каналов

Карта проверена на стенде с пультом FS-i6 (10 каналов, режим 2) и приёмником FS-iA6B.

| Канал | Орган пульта | Название | Что делает |
|---|---|---|---|
| CH1 | правый стик ←→ | AILERON | Крен — элероны (2000 = вправо) |
| CH2 | правый стик ↑↓ | ELEVATOR | Тангаж — лифт (2000 = от себя, нос вниз) |
| CH3 | левый стик ↑↓ | THROTTLE | Газ. 1000 мкс = выключен, 2000 мкс = максимум, без ограничений |
| CH4 | левый стик ←→ | RUDDER | Руль направления и рулевое колесо шасси (одна серва) |
| CH5 | SwA | ARM | Тумблер ARM — см. раздел про ARM ниже |
| CH6 | SwB | SWB | По умолчанию — закрылки: вниз, к себе — выпущены, вверх — убраны (см. ниже) |
| CH7 | SwC (3 положения) | SWC | По умолчанию — режим: вверх MANUAL, середина STABILIZE, вниз AUTO_TAKEOFF |
| CH8 | SwD | SWD | По умолчанию — RTH (домой), пока включён |
| CH9 | VrA | VRA | По умолчанию — сила стабилизации |
| CH10 | VrB | VRB | По умолчанию — скорость круиза |

CH6–CH10 — **что угодно одной строкой** в `include/config/Controls.h`: любой из
12 режимов, 10 функций (закрылки, тормоз, сброс груза, геозабор, пищалка…) и 7
крутилок. При включении платы фактическая раскладка печатается в монитор
порта. Всё про режимы и привязки — [AUTOPILOT_GUIDE.md](AUTOPILOT_GUIDE.md).

Все значения каналов — стандартный диапазон импульса приёмника 1000–2000 мкс, 1500 мкс — центр/нейтраль.

### Закрылки (флапероны)

Отдельных закрылков нет — их роль играют элероны. **SwB вниз** (к себе): оба элерона плавно, примерно за секунду, опускаются на одинаковый угол (`FLAPS_DEPLOYED_US` = 220 мкс ≈ 20° поворота качалки — меняется в `include/config/Config.h`). Это увеличивает подъёмную силу для взлёта и посадки на меньшей скорости. Крен стиком и автопилотом при этом работает как обычно — элероны расходятся в разные стороны, но уже вокруг опущенного положения. **SwB вверх** — так же плавно убираются. На OLED при выпущенных закрылках в первой строке горит `FL`.

При полном крене с выпущенными закрылками опускающийся элерон упирается в край хода раньше поднимающегося — это нормально, работает как дифференциал элеронов.

Выпуск закрылков обычно поднимает нос — будьте готовы чуть отдать ручку от себя; если эффект сильный, это настраивается уменьшением `FLAPS_DEPLOYED_US`.

---

## Каналы автопилота

Коротко — раскладка по умолчанию (`include/config/Controls.h`):

| Тумблер | Что делает |
|---|---|
| **SwC** (CH7) | вверх **MANUAL** · середина **STABILIZE** · вниз **AUTO_TAKEOFF** |
| **SwD** (CH8) | **RTH** — домой, пока включён |
| **SwB** (CH6) | закрылки |
| **VrA / VrB** (CH9/10) | сила стабилизации / скорость круиза |

- **STABILIZE — «стик задаёт угол».** Полный стик — крен 45°, тангаж 25°;
  отпустили — самолёт сам встал в горизонт. Газ — ваш.
- **AUTO_TAKEOFF.** После ARM ничего не происходит, пока вы сами не поднимете
  газ выше половины. Дальше: 0–1 с — газ плавно до 100%, крылья ровно; 1–3 с —
  тангаж +15°; дальше — +10°, пока вы не переключите SwC. Газ = максимум из
  стика и программы.
- **RTH.** Курс на точку ARM, высота 40 м, над домом — круги. Нужен GPS с
  3D-фиксом **до ARM**.

Все 12 режимов (ALT_HOLD, ACRO, CRUISE, LOITER, LAUNCH с руки, AUTO_LAND,
SOARING, RESCUE…), что каждому нужно из датчиков и как повесить его на
тумблер — [AUTOPILOT_GUIDE.md](AUTOPILOT_GUIDE.md). Режим, выбранный с
дашборда или наземной станции, держится, пока вы не щёлкнете тумблером
режима.

Стабилизация двигает рули и когда борт **не заармлен** — так на столе видно,
в какую сторону она отвечает на наклон. Интегратор при этом не копится.

Знаки углов (как на OLED и в логе): **крен R > 0 — правое крыло вниз, тангаж P > 0 — нос вверх.**

---

## ARM и failsafe

### Процедура ARM

- **ARM:** газ (CH3) внизу → тумблер **SwA (CH5) вниз, к себе** (на FS-i6 это CH5 = 2000; вверх = 1000). В Serial появится `ArmingManager: ARM`, на OLED — `ARMED`.
- **DISARM:** SwA вверх, от себя — мгновенно, в любой момент, мотор сразу останавливается.
- Если SwA перевели в ARM с газом не внизу или не прошли предполётные проверки — ARM **не** происходит (причина печатается в Serial). Нужно вернуть SwA вверх, убрать газ и снова перевести вниз.
- Если плату включили с SwA уже в положении ARM (вниз) — она **не** армится: прошивка должна сначала увидеть SwA вверху (OFF).

**ARM реально блокирует газ:** пока борт не armed, газ на ESC принудительно держится на минимуме независимо от стика. Перед взводом проверяется, что датчики, нужные выбранному режиму, отвечают — например, STABILIZE без живого IMU не заармится, пока не переключитесь в MANUAL. Всё равно ведите себя так, будто пропеллер может начать вращаться в любой момент после ARM.
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

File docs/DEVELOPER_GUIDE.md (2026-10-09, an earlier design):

# DEVELOPER_GUIDE.md — Руководство разработчика OpenPlaneProject

Техническая карта прошивки: какой файл за что отвечает, как текут данные от
приёмника и датчиков до сервоприводов, какие соглашения о знаках держат всю
цепочку вместе, как устроен веб-API и как расширять проект. Рассчитан на
разработчика, который пишет на C++ и хочет быстро сориентироваться в этом
репозитории (ветка `main`), а не на изучение основ языка или PlatformIO.
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

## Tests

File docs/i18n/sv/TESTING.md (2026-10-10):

# TESTING.md – tester, täckning och statisk analys

> 🌐 Den här sidan är en översättning av [det ryska originalet](../../TESTING.md). Om översättningen och originalet skiljer sig åt gäller originalet. Firmwaren skriver ut sina konsolmeddelanden på ryska, så de citeras oförändrade. Översättningen är gjord av AI och har inte granskats av personer med svenska som modersmål. Rapportera fel till [Damir Lebedev](https://github.com/damir-lebedev) eller i [ärendehanteraren](https://github.com/damir-lebedev/OpenPlaneProject/issues).

Firmwaren verifieras på två nivåer:

| Var | Kommando | Vad |
|---|---|---|
| **Dator (native)** | `pio test -e native` | Firmwarens headerfiler byggs på datorn oförändrade, med hårdvaran ersatt av styrbara attrapper: moduler, drivrutiner, flygsimuleringar i sluten slinga, hela ESP32-firmwaren (S3 och 38-pin) med varje sensorsats. Täckningen räknas |
| **Dator (native-stm32)** | `pio test -e native-stm32` | Hela STM32H743-firmwaren (`src/stm32/main.cpp`) ovanpå ett lager av STM32duino-attrapper: FreeRTOS-uppgifter, flash, MAVLink, sensorer på I2C och SPI |
| **Byggmatris** | `tools/build_matrix.sh` | 4 kort × 6 sensorsatser med `-Wall -Wextra (-Wshadow)`; varje varning i projektets kod är ett fel |
| **Kort** | `pio test -e esp32-s3` | `test_feedback` och `test_imu_orientation` på en riktig ESP32-S3 (den flashar en testfirmware; lägg tillbaka den vanliga efteråt: `pio run -t upload`) |
| **STM32-kort** | `pio test -e stm32h743-devebox -f test_blackbox_sd` | Den svarta lådan på ett **riktigt SD-kort** i DevEBox H743, plus `test_feedback` och `test_imu_orientation` på en Cortex-M7 – [nedan](#tester-på-stm32-kortet) |

Den arkitektoniska kontexten finns i [`ARCHITECTURE.md §12`](ARCHITECTURE.md#12-testbarhet).

---

## Snabbstart

```bash
pip install platformio gcovr        # en gång
# Windows: du behöver g++ i PATH, till exempel WinLibs (winlibs.com, zip UCRT):
# packa upp och lägg till mingw64\bin i PATH – ingen installation behövs
pio test -e native -e native-stm32  # alla native-tester (~1,5 min)
gcovr                               # täckning per fil (inställningar – gcovr.cfg)
tools/build_matrix.sh               # alla kort × alla sensorer (~25 min)
gcovr --html-details -o coverage/index.html   # HTML-rapport (coverage/ finns i .gitignore)

pio test -e native -f native/test_rc          # en svit
pio test -e native -f test_feedback           # återkopplingssimulering på datorn

# Banorna från simuleringarna i sluten slinga som CSV (för diagram):
OPENPLANE_SIM_DIR=/tmp/sim pio test -e native -f native/test_sim
# MAVLink-strömmen – för kontroll med en referensavkodare (pip install pymavlink):
OPENPLANE_MAVLINK_DUMP=/tmp/tlm.bin pio test -e native -f native/test_mavlink
python3 tools/check_mavlink.py /tmp/tlm.bin
```

Innan du räknar täckning efter ändringar i testerna hjälper det att börja från ett rent bygge: `rm -rf .pio/build/native`, annars hamnar räknarna från tidigare körningar i rapporten.

---

## Hur native-bygget fungerar

`[env:native]` i `platformio.ini`: `platform = native`, Unity, `-std=gnu++17`, `-D BOARD_ESP32_S3` (ESP32-S3:s stiftbeläggning), `-I test/native/support`, `-Wall -Wextra -Wshadow`, täckning med `--coverage` och `-fkeep-inline-functions -fkeep-static-functions` – utan dem ser gcov inte headerfunktioner som aldrig anropades och överskattar täckningen.

### Hårdvaruattrapper – `test/native/support/`

Headerfiler med samma namn och signaturer som Arduino-kärnan för ESP32 2.0.x, ESP-IDF och biblioteken, men ovanpå en simulerad värld i `namespace fake`:

| Fil | Ersätter | Vad simuleringen kan |
|---|---|---|
| `Arduino.h`, `Print.h`, `WString.h`, `Stream.h` | Arduino-kärnan | Makron (`constrain`, `sq`, `DEG_TO_RAD`…), `map()`, `String`, formatering med `print()` som i originalet. `ARDUINO` är avsiktligt **inte** definierad |
| `esp32-hal-fake.h` | tid, GPIO, ADC, LEDC, FreeRTOS, PSRAM, `ESP` | Klockan går bara framåt via `fake::advance*()`/`delay()`; `millis()/micros()` är `uint32_t`, som på ESP32 (överslag beter sig som på kortet). LEDC-kanaler, `pulseIn` efter den verkliga pulskvoten (syns bara om stiftets ingångsbuffert är påslagen), `analogReadMilliVolts` – spänningen från `fake::gpio().analogMv`. Uppgifter registreras (handtaget är inte null); `fake::runTask(task, n)` kör n varv av dess ändlösa slinga, `ulTaskNotifyTake` räknas som ett varv, `xTaskNotifyGive` som en räknare. FreeRTOS-mutexar är en ”upptagen”-flagga. `psramFound()`/`ps_malloc()`. Kritiska sektioner räknas |
| `HardwareSerial.h` | UART | Portar registreras efter nummer (`fake::uart(1)`); `pushRx()`, `txBytes()`, byte av hastighet i farten (`updateBaudRate`, historiken är `baudChanges()`). `Serial` = UART0 |
| `esp_partition.h` | ESP-IDF:s flashpartitioner | En partition är en vektor av byte med NOR-beteende: radering bara i sektorer om 4 KB, raderat = 0xFF, en skrivning sänker bara bitar (ett försök att höja en bit räknas – `bitRaises`); `beforeWrite` – ”strömmen gick”; räknare för läsningar, skrivningar och raderingar |
| `esp_system.h` | återställningsorsaken | `esp_reset_reason()` från `fake::chip().resetReason` |
| `Wire.h` | I2C | Enheter efter adress; `fake::RegisterMapDevice` – register med autoinkrement, en skrivlogg, fel (`present`, `failWrites`, `failReads`, `failReadIf`, `shortRead`), krokar `beforeRead`/`onRegisterWrite` |
| `SPI.h` | SPI | Enheter efter CS-stift; `fake::SpiRegisterMapDevice` – Bosch-/InvenSense-protokollet, `dummyBytes` före data |
| `Preferences.h` | NVS | Lagring i minnet, beteendet hos `begin(readOnly)`/`get*`/`getBytes` som i originalet; `failBegin` |
| `WiFi.h`, `WebServer.h` | Wi-Fi AP, HTTP | Resultatet av `softAP()` bestäms av testet; `WebServer::request(method, uri, body)` anropar den registrerade hanteraren; `fake::webServers()` – alla instanser |
| `U8g2lib.h` | U8g2 | I stället för pixlar – en lista över de strängar och rektanglar som ritats; `begin()/sendBuffer()` skickar byte genom en användarens byte-callback; `fake::displays()` |
| `soc/*.h` | ESP-IDF | `SOC_I2C_NUM = 2`, `GPIO_PIN_MUX_REG`, `PIN_INPUT_ENABLE` |

### STM32duino-lagret – `test/native/support_stm32/` (env `native-stm32`)

Det ligger i `-I` före `support/` och kompletterar samma attrapper med det som bara STM32duino har. `<Preferences.h>` i den här miljön är den **riktiga** `include/hal/stm32/compat/Preferences.h` ovanpå `KeyValueStore`.

| Fil | Ersätter | Vad den kan |
|---|---|---|
| `Arduino.h` | STM32duino-kärnan | stiften `PA0..PE15` (port·16 + nummer), `pin_size_t`, `PinMap_TIM` för servoutgångarnas stift, `HardwareTimer` (pulsen syns via `fake::timerPulseUs(pin)` och `pulseIn()`), `Uart`, `noInterrupts()` |
| `STM32FreeRTOS.h` | STM32duino FreeRTOS | `xTaskCreate` in i det gemensamma uppgiftsregistret (stacken i ord), `vTaskStartScheduler()` returnerar – testet kör själv uppgifterna (`fake::runTask`), `xPortGetFreeHeapSize` |
| `EEPROM.h` | EEPROM-emulering | en ”flash” på 8 KB (raderat = 0xFF) och en buffert, `fake::eeprom()` – räknare och korruption av avbilden |
| `SPI.h` | | `SPIMode` |

Tillagt i de gemensamma attrapperna för STM32: `TwoWire(sda, scl)`, `setSDA/SCL` och `fake::wireWithSda(pin)` (för att hitta kortets andra buss), `HardwareSerial(rx, tx)` och `fake::uartByRx(pin)`, `SPIClass::setSCLK/MISO/MOSI`.

### Kretsemulatorer och flygplansmodellen – `test/native/helpers/`

| Fil | Vad det är |
|---|---|
| `ChipEmulators.h` | LSM6DSV, ICM-45686 (med IPREG-indirekta register), QMC6309, SPL06-001, BMP581, u-blox NAV-PVT-ramar – registerkartor på I2C eller SPI, med data från ”världen” `World` (vinklar och hastigheter, höjd, lufthastighet, kurs, koordinater), i kretsens axlar med hänsyn till `IMU_ROTATION_CW_DEG` |
| `PlaneSim.h` | en flygplansmodell på ~1,2 kg: en punktmassa + rotation i roll/tippning, CL(α) med överstegring, luftmotstånd, dragkraft, vind, termik, mark |
| `SimHarness.h` | en sluten slinga: sändare → iBUS-ram → `IBusReceiver` → `PilotSwitches` → `Autopilot` → `FlightController` → PWM → roderutslag → `PlaneSim` → sensorer (inklusive ett pitotrör med två brusiga barometrar). En CSV-bana med `OPENPLANE_SIM_DIR` |

`test/native/helpers/TestSupport.h` är det som sviterna delar: `resetWorld()` (anropas från `setUp()`), ersättarna `FakeUart`/`FakeServo`/`FakeBoard` och för sensorerna (`FakeImu`, `FakeBaro`, `FakeMag`, `FakeGps`), rambyggaren `ibusFrame()`, riggarna `I2cRig`/`SpiRig` (en drivrutin ovanpå de riktiga `Esp32I2CBus`/`Esp32SpiBus` och `*RegisterDevice` med en simulerad krets).

Korttesterna (`test_feedback`, `test_imu_orientation`) är portabla: med `ARDUINO` – `setup()/loop()`, annars `main()`. Sviterna `test/native/*` byggs inte för kortet (`test_ignore` i `[esp32_common]` och `[env:stm32h743]`: mönstren skrivs ett per rad – åtskilda med mellanslag läser PlatformIO dem som ett). På STM32: `pio test -e stm32h743`.

---

## Testsviter

| Svit | Tester | Vad den kontrollerar |
|---|---|---|
| `native/test_hal` | 17 | `II2CBus`-hjälpare (NACK, kort läsning – bufferten lämnas orörd), `I2cRegisterDevice`, `SpiRegisterDevice` (läsbit, BMP388:s dummybyte), `Esp32I2CBus` (tidsgräns 5 ms), `Esp32SpiBus` (lägen 0–3), `Esp32UartPort` (8N1, stift), `Esp32ServoOutput` (50 Hz/14 bitar, pulsbegränsning, LEDC-fel, mätning via ingångsbufferten), `Esp32Board` (bussar, UART, kanalordning, AUX, summer) |
| `native/test_rc` | 16 | `RcChannelState`, `RcInput`, iBUS-tolkning: ramar som kommer i bitar, CRC, 12-bitarsvärden, sändarens failsafe, tidsgräns 500 ms (även över ett överslag i `micros()`), skräp, omsynkronisering |
| `native/test_control` | 21 | Klaffar (hastighet, första anropet, pauser), mixern (tecken, reversering, flaperoner), gas, ARM-tillståndsmaskinen och lägets sensorkontroller, utgångstabellen och pulsens självtest |
| `native/test_autopilot` | 22 | PID (D-term från sensorns hastighet, integral, anti-windup, `dt`), STABILIZE som vinkelläge, tidsbaserad autostart, ALT_HOLD med höjdrodret, glidflykt vid förlorad förbindelse |
| `native/test_autopilot_modes` | 31 | Alla 12 lägen och hur vart och ett reagerar på en saknad sensor, bindningstabellen och `static_assert`, funktioner och rattar, navigering (kurs, cirkel, hem, geofence), failsafe RTH/glidflykt, handstart, termikflygning, autotrimning (skrivs bara på marken) |
| `native/test_flight_controller` | 12 | En fullständig `FlightController`-cykel på de riktiga klasserna: prioriteterna förlorad förbindelse > ARM > spakar/autopilot > gas; AUX, `MOTOR_KILL`, summer |
| `native/test_imu` | 21 | MPU6050/6500/9250 och ICM-42688: identifiering, register, skalor, axelrotation och flygtekniska teckenkonventioner, bussfel, gyroskopkalibrering och kontrollen före flygning, monteringskalibrering från tre positioner, NVS, orienteringsfiltret |
| `native/test_baro_mag_gps` | 23 | `BarometerBase`, BMP388 över I2C och SPI, BME280/BMP280 mot Bosch-referensen, kompasser (kurs, hard-iron-kalibrering i NVS), u-blox M10 (CFG-VALSET, NAV-PVT, korrupta ramar, tidsgräns), `SensorSelection` |
| `native/test_sensors_new` | 23 | LSM6DSV (16X/32X, alternativ adress, SPI), ICM-45686 (indirekta register), QMC6309, SPL06-001 (formlerna i databladet), BMP581 (DRDY och reservvägen), pitotröret (nollpunkt, filter, densitet, förväxlade slangar, inaktuella data, en ”flygning” med bruset från två barometrar) |
| `native/test_storage` | 16 | `KeyValueStore` (omladdning, slitage – ett identiskt värde skrivs inte om, överfyllnad utan dataförlust, CRC, strömavbrott under radering, skräp, formatversion), `KvPreferences` (beter sig som ESP32:s NVS) |
| `native/test_mavlink` | 20 | Kodeken mot referensramar från pymavlink (v1, v2, signerade), CRC, omsynkronisering; telemetri: strömfrekvenser, HEARTBEAT/ATTITUDE/POSITION/HUD/GPS/SYS_STATUS, PID-parametrar (lista, läsning, skrivning, avvisning av dåliga värden), lägesbyte från marken, ARM från marken – nekas, uppdrag – 0, en överfull UART-buffert blockerar inte slingan |
| `native/test_blackbox` | 19 | Den svarta lådan: format och CRC, sektorringen på en NOR-attrapp (en ny partition utan radering, skräp raderas alltid, gamla flygningar raderas i sin helhet och bara för att frigöra utrymme, den senaste rörs aldrig, omslag vid ringens slut, huvudet efter en omstart, strömavbrott, en halvskriven post fångas av CRC), inspelning av en flygning på riktiga `FlightController`/`Autopilot`: start vid ARM och gas med förinspelning, stopp efter DISARM och ”står på marken”, förlorad förbindelse stoppar den inte, inspelning efter en felomstart, manuell start, händelser, batteri, flash tog slut i luften, en flygning längre än partitionen, hämtning i CRC-ramar med hastighetsbyte, konsolmenyn `k`, ingen partition – avstängd |
| `native/test_blackbox_scan` | 3 | En stickprovskontroll av ringen vid start mot den fullständiga: 300 slumpmässiga ringhistoriker × 5 provsteg (huvudet, numren och flyglistan stämmer, och när bilden inte går ihop – faller den tillbaka på den fullständiga avsökningen) och kostnaden på ett SD-område på 64 MB (≈530 läsningar i stället för 32 000) |
| `native/test_telemetry` | 28 | `LoopStats`, `LogSettings` (NVS, version), `DebugLogger` (alla kanaler, NAV), `DebugConsole` (meny, snabbtangenter, bussavsökning `b`, förbjudet under ARM, sparar bara utan ARM), `WebDebugServer` (rutter, JSON, brevlåda), `OledDisplay` (byte över I2C, ram, invertering vid förlorad förbindelse) |
| `native/test_sim` | 15 | Flygningar i sluten slinga av hela firmwaren med flygplansmodellen: återhämtning från krängning, CRUISE i sidvind, LOITER, RTH, failsafe RTH/glidflykt, geofence, autostart från bana, handstart, autolandning, termik, RESCUE ur en spiral, farthållning och överstegringsskydd, ett riktigt pitotrör i slingan, autotrimning av ett ”snett” flygplan, sensorfel under flygning (IMU, barometer, pitotrör, GPS) |
| `native/test_feedback_units` | 14 | Återkopplingsmodulerna en och en: hastighetskällor, i luften/på marken, RLS-skattningen, regulatorn, överstegringsindikatorer, avbrott av start/landning |
| `native/test_app` | 10 | `src/main.cpp` på ESP32-S3 med bänksatsen MPU6500/BMP581/QMC5883P/OLED: `loop()`-perioden, sändare → servon, ARM, lägen, förlorad förbindelse, konsol, panel, skärm, svart låda (en uppgift på kärna 0, inspelning vid gas, en flygning efter DISARM, `bb list`) |
| `native/test_app_lsm6dsv_pitot` | 9 | `src/main.cpp` på ESP32-S3 med flygsatsen: LSM6DSV + QMC6309 + SPL06 + BMP581 i pitotröret + GPS – identifiering av alla kretsar, pitotrörets nollpunkt och hastighet, höjd, hempunkt från GPS, STABILIZE efter vinklarna från kretsen, RTH till hempunkten, bussavsökning, panel |
| `native/test_app_icm45686_esp32dev` | 5 | `src/main.cpp` på **ESP32 38-pin** (`BOARD_ESP32_CLASSIC`) med satsen ICM-45686 + QMC6309 + SPL06 + BMP581: kortets stiftbeläggning, IPREG-filter, handstart, stabilisering och fart, avsökning av en enda buss |
| `native_stm32/test_app_stm32_lsm6dsv_pitot` | 9 | `src/stm32/main.cpp` på **STM32H743** med flygsatsen: uppgifter och prioriteter, en period på 2 ms, pitotröret, PWM-timrar och `pulseIn`, MAVLink under flygning, lägesbyte från GCS:en, inställningar skrivna av en bakgrundsuppgift till ”flashen”, skärmen på I2C1, konsolen |
| `native_stm32/test_app_stm32_icm45686_spi` | 4 | STM32H743 med ICM-45686 och BMP581 **över SPI** + QMC6309: korrupt flash vid start, ALT_HOLD från GCS:en håller höjden, förlorad förbindelse → RTH, synligt i MAVLink; omskrivning av en skadad avbild |
| `native_stm32/test_blackbox_sd` | 29 | Den svarta lådan på ett SD-kort: FAT32 (med och utan MBR, en katalog som sträcker sig över två kluster, brusposter, en främmande/fragmenterad/tom volym), `SdFileRegion` (delblock, cache, radering, gränser, fel), den riktiga drivrutinen `Stm32SdCard` ovanpå en attrapp av `HAL_SD` (4 bitar, reservhastigheter, omförsök, upptaget kort, ojusterade buffertar), ringen på kortet (omstart, strömavbrott, avsökningskostnad), markören ”ringen är tom”, inspelning av en flygning på en `FlightController`, en felomstart upptäckt via `RCC->RSR`, batteriets ADC, kortfel under flygning, ett långsamt kort, hämtning via konsolen, tangenten `D` |
| `native_stm32/test_app_stm32_blackbox_sd` | 3 | `src/stm32/main.cpp` med ett SD-kort: uppstarten hittar kortet och filen, uppgiften `bbox` skriver flygningen, slingans period sträcks inte ut, `bb list` |
| `native_stm32/test_app_stm32_no_sd` | 2 | `src/stm32/main.cpp` utan SD-kort: den svarta lådan är avstängd och förklarar varför, flygplanet flyger, menyn `k` går inte sönder |
| `test_feedback` | 10 | En flygplanssimulering i sluten slinga med en återkopplingsslinga (på datorn och på kortet) |
| `test_imu_orientation` | 5 | Kalibrering av IMU-monteringen på 300 slumpmässiga monteringar (på datorn och på kortet) |
| **Totalt** | **387** | 340 i `native` + 47 i `native-stm32` (plus 9 bara på kortet – `test_blackbox_sd`) |

### Tester på STM32-kortet

`test/test_blackbox_sd` är inte native: SDMMC-drivrutinen, kortet och tidtagningen är riktiga. Testerna körs i en FreeRTOS-uppgift, och bredvid den körs en uppgift som imiterar flygslingan med högsta prioritet (period 2 ms): den avbryter testerna mitt i kortåtkomster, precis som i firmwaren. Utan den kan man inte fånga felet som faktiskt hittades på kortet: vid avbrott flödade SDMMC:s FIFO över (`HAL_SD_ERROR_RX_OVERRUN`), vilket aldrig händer i en naken slinga.

| Test | Vad det kontrollerar |
|---|---|
| `reset_cause_is_a_normal_one` | återställningsorsaken (`RCC->RSR`) är varken watchdog eller spänningsfall |
| `card_is_detected_on_four_bit_bus` | kortet upptäcks på en 4-bitarsbuss vid 24 MHz |
| `file_is_found_and_contiguous` | `BLACKBOX.BIN` hittas på FAT32 och är sammanhängande |
| `multi_block_writes_work_at_every_length` | skrivning av 1, 2, 4 och 8 block i en enda åtkomst |
| `pages_write_with_bounded_latency_and_read_back_intact` | sidor på 256 B: den sämsta skrivningen < 250 ms (SD-gränsen), stadigt > 40 KB/s, läsning och radering |
| `header_scan_cost_on_the_whole_area` | kostnaden för att läsa ett sektorhuvud och för en fullständig avsökning |
| `storage_erase_all_write_flights_and_find_them_after_reopen` | radera allt, två flygningar med 20 000 poster vardera, ”omstart”: stickprovsavsökningen tar < 2 s, posterna läses i ordning med korrekt CRC; en tom ring känns igen på sin markör på < 100 ms |
| `blackbox_keeps_up_for_20_seconds_in_real_time` | den riktiga `BlackBox` med 500 Hz IMU i realtid: inte en enda förlorad post, flygningen kan läsas efter en ”omstart” |
| `the_flight_task_was_not_disturbed` | skrivningen till kortet rubbade inte imitatoruppgiftens period (avvikelse < 3 ms) |

Körning (ett kort med filen – `python tools/blackbox.py sd-prepare E:`; **testet raderar alla flygningar i filen**):

```bash
pio test -e stm32h743-devebox -f test_blackbox_sd
pio test -e stm32h743-devebox -f test_feedback -f test_imu_orientation
```

Sätt kortet i DFU-läge (på DevEBox – en tråd från BT0 till 3V3 plus RST, WinUSB-drivrutinen via Zadig; detaljer i [DEVELOPER_GUIDE](DEVELOPER_GUIDE.md#stm32h743)). STM32-konsolen är USB CDC: efter flashning dyker porten inte upp direkt, och `pio test` hinner ibland inte öppna den (”could not open port”) – kör i så fall `pio test ... --without-testing` och läs utdata med valfritt terminalprogram med DTR påslaget (testerna väntar upp till 60 s på att porten öppnas). Efter testerna väntar kortet på tangenten **`D`** – det startar om i DFU utan tråden.

Resultat på DevEBox H743 + ett 16 GB-kort (2026-10-02): `test_blackbox_sd` – 9/9, `test_feedback` – 10/10, `test_imu_orientation` – 5/5; siffrorna för kortets hastighet finns i [BLACKBOX.md](BLACKBOX.md#vad-som-mättes-på-kortet).

### Bänkfirmware – `test/bench/`

Det här är inte testsviter utan separata små PlatformIO-projekt som flashas till kortet i stället för flygfirmwaren (`pio test` ser dem inte: mappnamnen börjar inte med `test_`). Stift och gränser tas från den gemensamma `Config.h`.

| Projekt | Vad det gör |
|---|---|
| `bench/elevator_sweep` | Svänger höjdroderspaken (CH2) programmatiskt genom `ControlMixer` och `FlightOutputs`, som en levande spak: upp 100 % av utslaget, ned 60 %, mjukt, med pauser; 20 s arbete – 20 s i neutralläge. I ändlägena mäter den pulsen på utgångarna. Gas på minimum |

För att flasha: `pio run -d test/bench/elevator_sweep -t upload`. För att återställa flygfirmwaren: `pio run -e esp32-s3 -t upload`.

---

## Täckning

Den beräknas av `gcovr` över `include/` och `src/` (allt som går in i firmwaren), över båda native-miljöerna tillsammans: `gcovr -r . --filter include/ --filter src/ .pio/build/native .pio/build/native-stm32`.

| Lager | Rader | Grenar |
|---|---|---|
| `autopilot` | 920/943 (97,6 %) | 645/731 (88,2 %) |
| `autopilot/feedback` | 683/702 (97,3 %) | 501/570 (87,9 %) |
| `control` | 252/256 (98,4 %) | 171/189 (90,5 %) |
| `hal` | 98/102 (96,1 %) | 26/26 (100 %) |
| `hal/esp32` | 101/102 (99,0 %) | 21/22 (95,5 %) |
| `hal/stm32` | 149/158 (94,3 %) | 35/52 (67,3 %) |
| `rc` | 92/92 (100 %) | 41/42 (97,6 %) |
| `sensors` (alla) | 1444/1446 (99,9 %) | 716/835 (85,7 %) |
| `storage` | 220/220 (100 %) | 158/178 (88,8 %) |
| `telemetry` | 1413/1440 (98,1 %) | 1123/1269 (88,5 %) |
| `src` (`main.cpp`, `stm32/main.cpp`) | 118/123 (95,9 %) | 20/29 (69,0 %) |
| **Totalt** | **5490/5584 (98,3 %)** | **3457/3943 (87,7 %)**; funktioner 877/902 (97,2 %) |

Vad som förblir otäckt, och varför:

- **Handstart** (`TakeoffSequencer`: `WaitLaunch`, `launchDetected()`) – onåbar så länge `FeedbackConfig::TAKEOFF_HAND_LAUNCH = false`; den kommer med i testerna när konstanten blir konfigurerbar (flyttas till `Config.h`).
- **Kortberoende kod:** en utgång utan stift (`PIN_RUDDER = -1` förekommer bara på C3), en GPS utan TX-stift (C3) – native-testerna kör stiftbeläggningarna för S3, 38-pin och STM32, men inte C3 (C3 kontrolleras av byggmatrisen).
- **STM32:** kärnans felgrenar (ingen timer på stiftet, timerpoolen uttömd), meddelandet `FreeRTOS не запустился` (”FreeRTOS startade inte”) – på datorn returnerar `vTaskStartScheduler()` alltid.
- **Defensiva grenar** som inte kan nås via det publika API:t: `default`/`Count` i en `switch` över uppräkningar, `return "?"`.
- Filer utan körbara rader (`Config.h`, `Channels.h`, `FeedbackConfig.h`, strukturerna `ControlCommand`/`FlightOutputState`/`FlightSnapshot`/`FeedbackOutput`/`PhaseTargets`, makrona i `SensorSelection.h`, panelens HTML) syns inte i rapporten – de kompileras in i testerna, men gcov har inget att räkna i dem.

---
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

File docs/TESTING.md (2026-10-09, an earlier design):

# TESTING.md — тесты, покрытие и статический анализ

Прошивка проверяется на двух уровнях:

| Где | Команда | Что |
|---|---|---|
| **ПК (native)** | `pio test -e native` | Заголовки прошивки собираются на ПК без изменений, железо заменено управляемыми фейками: модули, драйверы, замкнутые симуляции полёта, прошивка ESP32 целиком (S3 и 38-pin) с каждым набором датчиков. Считается покрытие |
| **ПК (native-stm32)** | `pio test -e native-stm32` | Прошивка STM32H743 целиком (`src/stm32/main.cpp`) поверх слоя фейков STM32duino: задачи FreeRTOS, флеш, MAVLink, датчики на I2C и SPI |
| **Матрица сборок** | `tools/build_matrix.sh` | 4 платы × 6 наборов датчиков с `-Wall -Wextra (-Wshadow)`; любое предупреждение в коде проекта — ошибка |
| **Плата** | `pio test -e esp32-s3` | `test_feedback` и `test_imu_orientation` на реальном ESP32-S3 (прошивает тестовую прошивку; потом верните обычную: `pio run -t upload`) |
| **Плата STM32** | `pio test -e stm32h743-devebox -f test_blackbox_sd` | Чёрный ящик на **настоящей SD-карте** DevEBox H743, плюс `test_feedback` и `test_imu_orientation` на Cortex-M7 — [ниже](#тесты-на-плате-stm32) |

Архитектурный контекст — [`ARCHITECTURE.md §12`](ARCHITECTURE.md#12-тестируемость).

---

## Быстрый старт

```bash
pip install platformio gcovr        # один раз
# Windows: нужен g++ в PATH, например WinLibs (winlibs.com, zip UCRT):
# распаковать и добавить mingw64\bin в PATH — установка не нужна
pio test -e native -e native-stm32  # все нативные тесты (~1.5 мин)
gcovr                               # покрытие по файлам (настройки — gcovr.cfg)
tools/build_matrix.sh               # все платы × все датчики (~25 мин)
gcovr --html-details -o coverage/index.html   # HTML-отчёт (coverage/ в .gitignore)

pio test -e native -f native/test_rc          # один набор
pio test -e native -f test_feedback           # симуляция обратной связи на ПК

# Траектории замкнутых симуляций в CSV (для графиков):
OPENPLANE_SIM_DIR=/tmp/sim pio test -e native -f native/test_sim
# Поток MAVLink — на проверку эталонным декодером (pip install pymavlink):
OPENPLANE_MAVLINK_DUMP=/tmp/tlm.bin pio test -e native -f native/test_mavlink
python3 tools/check_mavlink.py /tmp/tlm.bin
```

Перед подсчётом покрытия после изменений в тестах полезно начать с чистой
сборки: `rm -rf .pio/build/native`, иначе в отчёт попадут счётчики прошлых
запусков.

---

## Как устроена нативная сборка

`[env:native]` в `platformio.ini`: `platform = native`, Unity, `-std=gnu++17`,
`-D BOARD_ESP32_S3` (распиновка ESP32-S3), `-I test/native/support`,
`-Wall -Wextra -Wshadow`, покрытие `--coverage` и
`-fkeep-inline-functions -fkeep-static-functions` — без них gcov не видит
ни разу не вызванные функции заголовков и завышает покрытие.

### Фейки железа — `test/native/support/`

Заголовки с теми же именами и сигнатурами, что у Arduino core ESP32 2.0.x,
ESP-IDF и библиотек, но поверх симулированного мира в `namespace fake`:

| Файл | Заменяет | Что умеет симуляция |
|---|---|---|
| `Arduino.h`, `Print.h`, `WString.h`, `Stream.h` | ядро Arduino | Макросы (`constrain`, `sq`, `DEG_TO_RAD`…), `map()`, `String`, форматирование `print()` как у оригинала. `ARDUINO` намеренно **не** определён |
| `esp32-hal-fake.h` | время, GPIO, АЦП, LEDC, FreeRTOS, PSRAM, `ESP` | Часы идут только по `fake::advance*()`/`delay()`; `millis()/micros()` — `uint32_t`, как на ESP32 (переполнение ведёт себя как на плате). LEDC-каналы, `pulseIn` по реальной скважности (виден, только если включён входной буфер пина), `analogReadMilliVolts` — напряжение из `fake::gpio().analogMv`. Задачи регистрируются (хэндл ненулевой); `fake::runTask(task, n)` выполняет n проходов её бесконечного цикла, `ulTaskNotifyTake` считается проходом, `xTaskNotifyGive` — счётчиком. Мьютексы FreeRTOS — флаг «занят». `psramFound()`/`ps_malloc()`. Критические секции считаются |
| `HardwareSerial.h` | UART | Порты регистрируются по номеру (`fake::uart(1)`); `pushRx()`, `txBytes()`, смена скорости на ходу (`updateBaudRate`, история — `baudChanges()`). `Serial` = UART0 |
| `esp_partition.h` | разделы флеша ESP-IDF | Раздел — вектор байт с поведением NOR: стирание только секторами 4 КБ, стёртое = 0xFF, запись только опускает биты (попытка поднять бит считается — `bitRaises`); `beforeWrite` — «пропало питание»; счётчики чтений, записей, стираний |
| `esp_system.h` | причина перезагрузки | `esp_reset_reason()` из `fake::chip().resetReason` |
| `Wire.h` | I2C | Устройства по адресу; `fake::RegisterMapDevice` — регистры с автоинкрементом, журнал записей, сбои (`present`, `failWrites`, `failReads`, `failReadIf`, `shortRead`), хуки `beforeRead`/`onRegisterWrite` |
| `SPI.h` | SPI | Устройства по пину CS; `fake::SpiRegisterMapDevice` — протокол Bosch/InvenSense, `dummyBytes` перед данными |
| `Preferences.h` | NVS | Хранилище в памяти, поведение `begin(readOnly)`/`get*`/`getBytes` как у оригинала; `failBegin` |
| `WiFi.h`, `WebServer.h` | Wi-Fi AP, HTTP | Результат `softAP()` задаёт тест; `WebServer::request(метод, uri, тело)` вызывает зарегистрированный обработчик; `fake::webServers()` — все экземпляры |
| `U8g2lib.h` | U8g2 | Вместо пикселей — список нарисованных строк и прямоугольников; `begin()/sendBuffer()` гоняют байты через пользовательский byte-callback; `fake::displays()` |
| `soc/*.h` | ESP-IDF | `SOC_I2C_NUM = 2`, `GPIO_PIN_MUX_REG`, `PIN_INPUT_ENABLE` |

### Слой STM32duino — `test/native/support_stm32/` (env `native-stm32`)

Лежит в `-I` раньше `support/` и дополняет те же фейки тем, что есть только у
STM32duino. `<Preferences.h>` в этой среде — **настоящий**
`include/hal/stm32/compat/Preferences.h` поверх `KeyValueStore`.

| Файл | Заменяет | Что умеет |
|---|---|---|
| `Arduino.h` | ядро STM32duino | пины `PA0..PE15` (порт·16 + номер), `pin_size_t`, `PinMap_TIM` для пинов сервовыходов, `HardwareTimer` (импульс виден `fake::timerPulseUs(pin)` и `pulseIn()`), `Uart`, `noInterrupts()` |
| `STM32FreeRTOS.h` | STM32duino FreeRTOS | `xTaskCreate` в общий реестр задач (стек в словах), `vTaskStartScheduler()` возвращается — задачи тест крутит сам (`fake::runTask`), `xPortGetFreeHeapSize` |
| `EEPROM.h` | EEPROM-эмуляция | «флеш» 8 КБ (стёрт = 0xFF) и буфер, `fake::eeprom()` — счётчики и порча образа |
| `SPI.h` | | `SPIMode` |

В общих фейках для STM32 добавлено: `TwoWire(sda, scl)`, `setSDA/SCL` и
`fake::wireWithSda(pin)` (найти вторую шину платы), `HardwareSerial(rx, tx)` и
`fake::uartByRx(pin)`, `SPIClass::setSCLK/MISO/MOSI`.

### Эмуляторы чипов и модель самолёта — `test/native/helpers/`

| Файл | Что это |
|---|---|
| `ChipEmulators.h` | LSM6DSV, ICM-45686 (с косвенными регистрами IPREG), QMC6309, SPL06-001, BMP581, кадры NAV-PVT u-blox — регистровые карты на I2C или SPI, данные из «мира» `World` (углы и скорости, высота, воздушная скорость, курс, координаты), в осях чипа с учётом `IMU_ROTATION_CW_DEG` |
| `PlaneSim.h` | модель самолёта ~1.2 кг: точка с массой + вращение по крену/тангажу, CL(α) со сваливанием, сопротивление, тяга, ветер, термики, земля |
| `SimHarness.h` | замкнутый контур: пульт → кадр iBUS → `IBusReceiver` → `PilotSwitches` → `Autopilot` → `FlightController` → ШИМ → отклонения рулей → `PlaneSim` → датчики (в том числе трубка Пито на двух шумных барометрах). CSV-траектория при `OPENPLANE_SIM_DIR` |

`test/native/helpers/TestSupport.h` — общее для наборов: `resetWorld()`
(вызывается из `setUp()`), дублёры `FakeUart`/`FakeServo`/`FakeBoard` и
датчиков (`FakeImu`, `FakeBaro`, `FakeMag`, `FakeGps`), сборщик кадров
`ibusFrame()`, стенды `I2cRig`/`SpiRig` (драйвер поверх настоящих
`Esp32I2CBus`/`Esp32SpiBus` и `*RegisterDevice` с симулированным чипом).

Тесты на плате (`test_feedback`, `test_imu_orientation`) переносимые: при
`ARDUINO` — `setup()/loop()`, иначе `main()`. Наборы `test/native/*` на плате
не собираются (`test_ignore` в `[esp32_common]` и `[env:stm32h743]`: шаблоны —
каждый на своей строке, через пробел PlatformIO читает их как один).
На STM32: `pio test -e stm32h743`.

---

## Наборы тестов

| Набор | Тестов | Что проверяет |
|---|---|---|
| `native/test_hal` | 17 | Помощники `II2CBus` (NACK, короткое чтение — буфер не трогается), `I2cRegisterDevice`, `SpiRegisterDevice` (бит чтения, фиктивный байт BMP388), `Esp32I2CBus` (таймаут 5 мс), `Esp32SpiBus` (режимы 0–3), `Esp32UartPort` (8N1, пины), `Esp32ServoOutput` (50 Гц/14 бит, ограничение импульса, отказ LEDC, измерение через входной буфер), `Esp32Board` (шины, UART, порядок каналов, AUX, пищалка) |
| `native/test_rc` | 16 | `RcChannelState`, `RcInput`, разбор iBUS: кадры по частям, CRC, 12-битные значения, failsafe пульта, таймаут 500 мс (и через переполнение `micros()`), мусор, пересинхронизация |
| `native/test_control` | 21 | Закрылки (скорость, первый вызов, паузы), микшер (знаки, реверс, флапероны), газ, автомат ARM и проверки датчиков режима, таблица выходов и самопроверка импульсов |
| `native/test_autopilot` | 22 | ПИД (D по скорости датчика, интеграл, anti-windup, `dt`), STABILIZE как режим углов, автовзлёт по времени, ALT_HOLD рулём высоты, планирование при потере связи |
| `native/test_autopilot_modes` | 31 | Все 12 режимов и реакция каждого на отсутствие датчика, таблица привязок и `static_assert`, функции и крутилки, навигация (курс, круг, дом, геозабор), failsafe RTH/планирование, запуск с руки, парение, автотриммер (запись только на земле) |
| `native/test_flight_controller` | 12 | Полный такт `FlightController` на настоящих классах: приоритеты потеря связи > ARM > стики/автопилот > газ; AUX, `MOTOR_KILL`, пищалка |
| `native/test_imu` | 21 | MPU6050/6500/9250 и ICM-42688: опознание, регистры, масштабы, поворот осей и авиационные знаки, ошибки шины, калибровка гироскопа и предполётная проверка, калибровка установки по трём позам, NVS, фильтр ориентации |
| `native/test_baro_mag_gps` | 23 | `BarometerBase`, BMP388 по I2C и SPI, BME280/BMP280 по эталону Bosch, компасы (курс, hard-iron калибровка в NVS), u-blox M10 (CFG-VALSET, NAV-PVT, битые кадры, таймаут), `SensorSelection` |
| `native/test_sensors_new` | 23 | LSM6DSV (16X/32X, запасной адрес, SPI), ICM-45686 (косвенные регистры), QMC6309, SPL06-001 (формулы датащита), BMP581 (DRDY и запасной путь), трубка Пито (ноль, фильтр, плотность, перепутанные шланги, устаревшие данные, «полёт» с шумом двух барометров) |
| `native/test_storage` | 16 | `KeyValueStore` (перезагрузка, износ — одинаковое не пишется, переполнение без потери данных, CRC, пропажа питания при стирании, мусор, версия формата), `KvPreferences` (поведение как у NVS ESP32) |
| `native/test_mavlink` | 20 | Кодек против эталонных кадров pymavlink (v1, v2, подписанный), CRC, пересинхронизация; телеметрия: частоты потоков, HEARTBEAT/ATTITUDE/POSITION/HUD/GPS/SYS_STATUS, параметры ПИД (список, чтение, запись, отказ плохих значений), смена режима с земли, ARM с земли — отказ, миссии — 0, переполненный буфер UART не блокирует цикл |
| `native/test_blackbox` | 19 | Чёрный ящик: формат и CRC, кольцо секторов на NOR-фейке (свежий раздел без стирания, мусор стирается всегда, старые полёты — целиком и только ради места, последний не трогается, переход через конец кольца, голова после перезагрузки, обрыв питания, недописанная запись по CRC), запись полёта на настоящих `FlightController`/`Autopilot`: старт по ARM и газу с предзаписью, стоп после DISARM и «стоит на земле», потеря связи не останавливает, запись после сбойной перезагрузки, вручную, события, батарея, флеш кончился в воздухе, полёт длиннее раздела, выгрузка кадрами с CRC и сменой скорости, меню консоли `k`, нет раздела — выключен |
| `native/test_blackbox_scan` | 3 | Выборочная сверка кольца при включении против полной: 300 случайных историй колец × 5 шагов проб (голова, номера и список полётов совпадают, а когда картина не сходится — уступает полной) и стоимость на области SD 64 МБ (≈530 чтений вместо 32 тысяч) |
| `native/test_telemetry` | 28 | `LoopStats`, `LogSettings` (NVS, версия), `DebugLogger` (все каналы, NAV), `DebugConsole` (меню, горячие клавиши, опрос шин `b`, запрет при ARM, сохранение только без ARM), `WebDebugServer` (маршруты, JSON, почтовый ящик), `OledDisplay` (байты по I2C, кадр, инверсия при потере связи) |
| `native/test_sim` | 15 | Замкнутые полёты всей прошивки с моделью самолёта: выход из крена, CRUISE в боковой ветер, LOITER, RTH, failsafe RTH/планирование, геозабор, автовзлёт с полосы, запуск с руки, автопосадка, термик, RESCUE из спирали, удержание скорости и защита от сваливания, настоящая трубка Пито в контуре, автотриммер «кривого» самолёта, отказы датчиков в полёте (IMU, барометр, трубка Пито, GPS) |
| `native/test_feedback_units` | 14 | Модули обратной связи по отдельности: источники скорости, в воздухе/на земле, RLS-оценка, регулятор, признаки сваливания, отмены взлёта/посадки |
| `native/test_app` | 10 | `src/main.cpp` на ESP32-S3 со стендовым набором MPU6500/BMP581/QMC5883P/OLED: период `loop()`, пульт → сервы, ARM, режимы, потеря связи, консоль, дашборд, экран, чёрный ящик (задача на ядре 0, запись по газу, полёт после DISARM, `bb list`) |
| `native/test_app_lsm6dsv_pitot` | 9 | `src/main.cpp` на ESP32-S3 с лётным набором: LSM6DSV + QMC6309 + SPL06 + BMP581 в трубке + GPS — опознание всех чипов, ноль трубки и скорость, высота, дом по GPS, STABILIZE по углам с чипа, RTH на дом, опрос шин, дашборд |
| `native/test_app_icm45686_esp32dev` | 5 | `src/main.cpp` на **ESP32 38-pin** (`BOARD_ESP32_CLASSIC`) с набором ICM-45686 + QMC6309 + SPL06 + BMP581: распиновка платы, фильтры IPREG, запуск с руки, стабилизация и скорость, опрос одной шины |
| `native_stm32/test_app_stm32_lsm6dsv_pitot` | 9 | `src/stm32/main.cpp` на **STM32H743** с лётным набором: задачи и приоритеты, период 2 мс, трубка, таймеры ШИМ и `pulseIn`, MAVLink в полёте, смена режима из GCS, запись настроек фоновой задачей во «флеш», экран на I2C1, консоль |
| `native_stm32/test_app_stm32_icm45686_spi` | 4 | STM32H743 с ICM-45686 и BMP581 **по SPI** + QMC6309: испорченный флеш при включении, ALT_HOLD из GCS держит высоту, потеря связи → RTH, видно в MAVLink; перезапись битого образа |
| `native_stm32/test_blackbox_sd` | 29 | Чёрный ящик на SD-карте: FAT32 (MBR и без, каталог на двух кластерах, шумовые записи, чужой/разбросанный/пустой том), `SdFileRegion` (неполные блоки, кэш, стирание, границы, сбои), настоящий драйвер `Stm32SdCard` поверх фейкового `HAL_SD` (4 бита, запасные скорости, повтор, занятая карта, невыровненные буферы), кольцо на карте (перезагрузка, пропажа питания, стоимость сверки), метка «кольцо пусто», запись полёта на `FlightController`, сбойная перезагрузка по `RCC->RSR`, АЦП батареи, ошибки карты в полёте, медленная карта, выгрузка по консоли, клавиша `D` |
| `native_stm32/test_app_stm32_blackbox_sd` | 3 | `src/stm32/main.cpp` с картой: загрузка находит карту и файл, задача `bbox` пишет полёт, период цикла не растягивается, `bb list` |
| `native_stm32/test_app_stm32_no_sd` | 2 | `src/stm32/main.cpp` без карты: ящик выключен и объясняет почему, самолёт летает, меню `k` не ломается |
| `test_feedback` | 10 | Замкнутая симуляция самолёта с контуром обратной связи (на ПК и на плате) |
| `test_imu_orientation` | 5 | Калибровка установки IMU на 300 случайных установках (на ПК и на плате) |
| **Всего** | **387** | 340 в `native` + 47 в `native-stm32` (плюс 9 только на плате — `test_blackbox_sd`) |
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

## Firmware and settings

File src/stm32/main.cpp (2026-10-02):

// ============================================================
// AEROS-001 FLIGHT CONTROLLER — STM32H743VIT6
//
// Та же прошивка, что src/main.cpp для ESP32-S3: те же датчики,
// автопилот, тумблеры (config/Controls.h), консоль и экран. Отличия
// платформы спрятаны ниже уровня этого файла:
//   - плата — Stm32Board (hal/stm32/): шины, UART, таймеры PWM;
//   - калибровки и настройки — во флеше, не в NVS: заголовок
//     <Preferences.h> подменяет hal/stm32/compat/Preferences.h
//     (KeyValueStore в последнем секторе флеша);
//   - вместо Wi-Fi-дашборда — телеметрия MAVLink по радиомодему на
//     UART4 (QGroundControl / Mission Planner);
//   - задачи FreeRTOS (библиотека STM32duino FreeRTOS) на одном ядре
//     с вытеснением по приоритету (hal/Rtos.h):
//       flight  (приоритет 5) — полётный цикл каждые LOOP_PERIOD_MS:
//                FlightController, MAVLink, лог, консоль;
//       oled    (1) — экран раз в 200 мс (OledDisplay);
//       storage (1) — запись настроек во флеш: стирание сектора
//                длится секунды, полётная задача его вытесняет;
//       bbox    (2) — чёрный ящик: снимки полётного цикла пишутся на
//                SD-карту (SDMMC1) блоками по 512 байт.
//
// На железе проверена голая плата DevEBox H743 (без датчиков и серв):
// загрузка, консоль по USB, SD-карта и чёрный ящик. Датчики, ШИМ на серво
// и iBUS на STM32 ещё ждут стенда. Первое включение с датчиками: консоль
// (env stm32h743-devebox — USB CDC; stm32h743 — LPUART1 115200, PA9/PA10),
// 'b' — опрос шин I2C, 's' — датчики, 'p' — импульсы на выходах (пропеллер
// снять!), 'D' — перезагрузка в загрузчик USB DFU.
// ============================================================

#include <Arduino.h>

#include "autopilot/Autopilot.h"
#include "autopilot/PilotSwitches.h"
#include "config/Config.h"
#include "control/ArmingManager.h"
#include "control/ControlMixer.h"
#include "control/FlightController.h"
#include "control/FlightOutputs.h"
#include "control/ThrottleManager.h"
#include "hal/Rtos.h"
#include "hal/SdFileRegion.h"
#include "hal/stm32/Stm32Board.h"
#include "hal/stm32/Stm32FlashStorage.h"
#include "hal/stm32/Stm32SdCard.h"
#include "rc/IBusReceiver.h"
#include "sensors/SensorInterface.h"
#include "sensors/SensorSelection.h"
#include "sensors/airspeed/AirspeedSensor.h"
#include "telemetry/BlackBox.h"
#include "telemetry/BlackBoxStorage.h"
#include "telemetry/DebugConsole.h"
#include "telemetry/DebugLogger.h"
#include "telemetry/LoopStats.h"
#include "telemetry/MavlinkTelemetry.h"
#include "telemetry/OledDisplay.h"


// ------------------------------------------------------------
// Железо.
// ------------------------------------------------------------

Stm32Board board;

#if defined(ARDUINO_ARCH_STM32)
void stm32RebootToBootloader();   // src/stm32/bootloader.cpp
#endif


// ------------------------------------------------------------
// Датчики — как на ESP32 (sensors/SensorSelection.h).
// ------------------------------------------------------------

auto imuDevice = SELECTED_IMU_DEVICE(board);
SelectedImu imuSensor(imuDevice);

auto baroDevice = SELECTED_BARO_DEVICE(board);
SelectedBaro baroSensor(baroDevice);

#if SENSOR_MAG != SENSOR_MAG_NONE
auto magDevice = SELECTED_MAG_DEVICE(board);
SelectedMag magSensor(magDevice);
MagnetometerSensor* const magnetometer = &magSensor;
#else
MagnetometerSensor* const magnetometer = nullptr;
#endif

#if SENSOR_GPS != SENSOR_GPS_NONE
SelectedGps gpsSensor(board.gpsUart());
GpsSensor* const gpsReceiver = &gpsSensor;
#else
GpsSensor* const gpsReceiver = nullptr;
#endif

#if SENSOR_AIRSPEED != SENSOR_AIRSPEED_NONE
auto pitotDevice = SELECTED_PITOT_DEVICE(board);
SelectedPitotBaro pitotBaro(pitotDevice, "PITOT-BMP581");
PitotDualBaroAirspeed pitotSensor(pitotBaro, baroSensor);
AirspeedSensor* const airspeedSensor = &pitotSensor;
#else
AirspeedSensor* const airspeedSensor = nullptr;
#endif


// ------------------------------------------------------------
// Управление полётом.
// ------------------------------------------------------------

IBusReceiver ibusReceiver(board.rcUart());
ControlMixer controlMixer;
ThrottleManager throttleManager;
FlightOutputs flightOutputs(board);

Autopilot autopilot(&imuSensor, &baroSensor, magnetometer, gpsReceiver, airspeedSensor);
PilotSwitches pilotSwitches(&autopilot);
ArmingManager armingManager(&autopilot);

FlightController flightController(
    ibusReceiver,
    controlMixer,
    throttleManager,
    armingManager,
    flightOutputs,
    &autopilot,
    &pilotSwitches
);


// ------------------------------------------------------------
// Отладка и телеметрия.
// ------------------------------------------------------------

LoopStats loopStats;

// Чёрный ящик: файл BLACKBOX.BIN в корне FAT32-карты, заранее созданный на
// ПК (tools/blackbox.py sd-prepare). Нет карты или файла — ящик выключен.
Stm32SdCard sdCard;
SdFileRegion blackBoxFile(sdCard, Config::BLACKBOX_SD_FILE, Config::BLACKBOX_SD_MAX_BYTES);
BlackBoxStorage blackBoxStorage(blackBoxFile);
BlackBox blackBox(flightController, autopilot, loopStats, blackBoxStorage, &pilotSwitches);

DebugLogger debugLogger(flightController, &autopilot, &loopStats);
DebugConsole debugConsole(flightController, flightOutputs, autopilot, debugLogger, &board, &blackBox);
MavlinkTelemetry mavlink(*board.telemetryUart(), flightController, &autopilot, &loopStats);
OledDisplay oledDisplay(flightController, &autopilot, loopStats);


static void printBanner()
{
    Serial.println();
    Serial.println("=================================");
    Serial.println(" AEROS-001 FLIGHT CONTROLLER");
    Serial.println(" STM32H743 / FreeRTOS");
    Serial.println("=================================");
    Serial.println();
}

// SD-карта и файл чёрного ящика: что нашлось — в консоль, дальше BlackBox
// сам сверяет сектора и выключается, если места для записи нет.
static void setupBlackBox()
{
    Serial.print("SD-карта: ");
    if (!sdCard.begin())
    {
        Serial.print("нет ответа (код ");
        Serial.print(static_cast<unsigned long>(sdCard.initError()));
        Serial.println(") — карта не вставлена или не опознана");
    }
    else
    {
        Serial.print(static_cast<unsigned long>(sdCard.blockCount() / 2048));
        Serial.print(" МБ, SDMMC ");
        Serial.print(static_cast<unsigned long>(48 / (2 * sdCard.clockDivider())));   // ядро SDMMC — 48 МГц
        Serial.print(" МГц, 4 бита; файл ");
        Serial.print(Config::BLACKBOX_SD_FILE);
        Serial.print(": ");
        const Fat32::Result found = blackBoxFile.begin();
        Serial.println(Fat32::describe(found));
    }

    const uint32_t start = millis();
    blackBox.begin();   // сверка стёртого места, очередь, задача записи
    Serial.print("BlackBox: готов за ");
    Serial.print(static_cast<unsigned long>(millis() - start));
    Serial.println(" мс");
}

// Как на ESP32: опознать датчики и откалибровать ответившие (самолёт
// неподвижен ~2 с).
static void setupSensors()
{
    if (imuSensor.begin())
    {
        imuSensor.calibrate();
    }

    if (baroSensor.begin())
    {
        baroSensor.calibrateAltitude();
    }

#if SENSOR_MAG != SENSOR_MAG_NONE
    if (magSensor.begin())
    {
        delay(25);
        magSensor.update();
        imuSensor.setYaw(magSensor.getMagData().headingDegrees);
    }
#endif

#if SENSOR_GPS != SENSOR_GPS_NONE
    gpsSensor.begin();
#endif

#if SENSOR_AIRSPEED != SENSOR_AIRSPEED_NONE
    pitotSensor.begin();
#endif

    autopilot.begin();
}


// ------------------------------------------------------------
// Задачи.
// ------------------------------------------------------------

static void flightTask(void*)
{
    TickType_t lastWake = xTaskGetTickCount();

    for (;;)
    {
        const uint32_t start = micros();

        flightController.update();
        mavlink.update();
        debugLogger.update();
        debugConsole.update();

        const uint32_t workUs = micros() - start;
        loopStats.record(workUs);
        blackBox.update(workUs);   // снимок в очередь; на карту пишет задача bbox

        // После долгой блокировки (калибровка из консоли) не догоняем
        // пропущенные такты пачкой.
        if (xTaskGetTickCount() - lastWake > pdMS_TO_TICKS(100))
        {
            lastWake = xTaskGetTickCount();
        }
        vTaskDelayUntil(&lastWake, pdMS_TO_TICKS(Config::LOOP_PERIOD_MS));
    }
}

static void storageTask(void*)
{
    for (;;)
    {
        Stm32FlashStorage::instance().service();
        vTaskDelay(pdMS_TO_TICKS(100));
    }
}


// Вызывается ядром Arduino, а не из кода проекта.
// cppcheck-suppress unusedFunction
void setup()
{
    Serial.begin(115200);
    delay(200);

    printBanner();

    board.begin();               // шины I2C/SPI
    flightOutputs.begin();       // PWM-выходы, сразу в безопасное положение
    flightOutputs.setFailsafe();

    // Калибровки и настройки: образ из последнего сектора флеша.
    KeyValueStore& settings = Stm32FlashStorage::store();
    settings.mount();
    Serial.print("Настройки во флеше: ");
    if (settings.wasCorrupt())
    {
        Serial.println("образ повреждён — значения по умолчанию, калибровки повторить");
    }
    else if (settings.bytesUsed() <= KeyValueStore::HEADER_SIZE)
    {
        Serial.println("пусто — значения по умолчанию");
    }
    else
    {
        Serial.print(static_cast<unsigned>(settings.bytesUsed()));
        Serial.println(" байт");
    }

    setupSensors();

    flightController.begin();    // приёмник iBUS
    mavlink.begin();             // радиомодем
    oledDisplay.begin(board.displayI2c());
    setupBlackBox();             // последним: задача записи начинает готовить место

    Serial.println();
    Serial.println("Готово. iBUS 115200 бод, 10 каналов; MAVLink 57600 бод на UART4 (PD0/PD1).");
    Serial.println("ARM: SwA вниз, к себе (CH5=2000) при газе внизу. DISARM: SwA вверх.");
    pilotSwitches.printBindings();
    debugLogger.begin();
#if defined(ARDUINO_ARCH_STM32)
    debugConsole.setBootloaderHook(stm32RebootToBootloader);   // 'D' — перепрошивка без BOOT0
#endif
    debugConsole.printHint();
    Serial.println();

    // Стек в байтах; полётной задаче — с запасом под printf лога.
    Rtos::startTask(flightTask, "flight", 16384, nullptr, Rtos::PRIORITY_FLIGHT);
    Rtos::startTask(storageTask, "storage", 2048, nullptr, Rtos::PRIORITY_BACKGROUND);
    vTaskStartScheduler();       // не возвращается

    Serial.println("FreeRTOS не запустился (мало памяти?)");
}


// Не вызывается: после vTaskStartScheduler() работают только задачи.
// cppcheck-suppress unusedFunction
void loop()
{
}

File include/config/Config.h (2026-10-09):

#pragma once
#include <stdint.h>

#if defined(BOARD_STM32H743)
#include <Arduino.h>   // PA0...PE15 — номера пинов варианта STM32duino
#endif

// ============================================================
// 1. CONFIGURATION
// Все постоянные параметры проекта находятся здесь.
// Логика классов ниже не должна содержать "магических" пинов,
// таймаутов и прочих настроек.
// ============================================================

namespace Config
{
    // --------------------------------------------------------
    // Hardware pinout — выбирается платой сборки (platformio.ini
    // задаёт ровно один из макросов ниже через build_flags, env
    // esp32-c3 / esp32-s3 / esp32-dev / stm32h743). Чтобы добавить новую плату:
    // скопируйте блок, поменяйте номера пинов, добавьте #elif
    // и одноимённый [env:...] в platformio.ini.
    //
    // Основная плата — STM32H743 (DevEBox H743, блок BOARD_STM32H743).
    // Вживую проверены ESP32-S3 N16R8 (прежняя основная плата) и ESP32-C3
    // SuperMini (старый прототип). Распиновка esp32-dev подобрана
    // по документации чипа (не заняты флешем/USB, не input-only) и
    // требует проверки под конкретную плату.
    // --------------------------------------------------------

#if defined(BOARD_ESP32_S3)
    // ESP32-S3 N16R8 (DevKitC-1-клон с двумя USB-C "USB"/"COM") —
    // прежний основной лётный контроллер. Проверено вживую: сервы/ESC, iBUS,
    // обе I2C-шины (шина датчиков — ещё на GPIO8/9, см. ниже).
    // Не используются: GPIO0/45/46 (strapping), 19/20 (USB D-/D+),
    // 26-32 (SPI flash), 33-37 (octal PSRAM у N16R8), 43/44 (UART0 ->
    // разъём "COM", на нём Serial), 48 (RGB-светодиод на плате).
    // GPIO3 — тоже strapping (источник JTAG), но влияет, только если
    // это задано в eFuse (по умолчанию нет), — поэтому под вход АЦП
    // датчика тока он годится.
    //
    // Раскладка подогнана под плату полётника (docs/FC_BOARD.md): пины
    // каждого блока разъёмов идут подряд по гребёнке DevKit, чтобы
    // плата разводилась в один слой без пересечений.
    constexpr uint8_t PIN_AILERON_LEFT  = 4;
    constexpr uint8_t PIN_AILERON_RIGHT = 5;
    constexpr uint8_t PIN_ELEVATOR      = 6;
    constexpr uint8_t PIN_ESC           = 7;
    constexpr int8_t  PIN_RUDDER        = 18;  // руль направления + колесо
    constexpr uint8_t PIN_IBUS          = 17;
    // Шина датчиков — правый ряд DevKit, рядом с OLED: там же 3V3-зона
    // платы. На стенде проверена на GPIO8/9 — переезд на 41/42 это
    // только другие пины той же шины Wire.
    constexpr uint8_t PIN_I2C_SDA       = 41;
    constexpr uint8_t PIN_I2C_SCL       = 42;

    // Вторая I2C-шина (Wire1) — только OLED-дисплей. Отдельно от
    // датчиков, чтобы отрисовка кадра (~25 мс на 400 кГц) не
    // задерживала опрос IMU.
    constexpr int8_t PIN_I2C2_SDA       = 1;
    constexpr int8_t PIN_I2C2_SCL       = 2;

    // SPI (ICM42688 + BMP388, общая шина, разные CS) — GPIO11-13
    // это дефолтная распиновка FSPI на большинстве S3-DevKitC плат.
    // Только для стенда: на плате полётника SPI не разведён (датчики
    // там на I2C), GPIO11-14 остаются свободными. GPIO21 на плате —
    // выход LIGHT (ниже); CS барометра трогается, только если в
    // SensorSelection.h выбран барометр по SPI.
    constexpr uint8_t PIN_SENSOR_SPI_SCK  = 12;
    constexpr uint8_t PIN_SENSOR_SPI_MISO = 13;
    constexpr uint8_t PIN_SENSOR_SPI_MOSI = 11;
    constexpr uint8_t PIN_SPI_CS_IMU      = 14;
    constexpr uint8_t PIN_SPI_CS_BARO     = 21;

    // Второй UART — GPS (отдельно от iBUS, который на UART1/GPIO17).
    // У S3 всего 3 аппаратных UART (0/1/2); UART0 занят Serial
    // (GPIO43/44 -> разъём "COM", см. platformio.ini) — GPS на UART2.
    // Правый ряд DevKit, сразу под шиной датчиков: разъём GPS и
    // I2C-разъём его компаса стоят рядом.
    constexpr int8_t PIN_GPS_RX = 39;
    constexpr int8_t PIN_GPS_TX = 40;
    constexpr uint8_t UART_NUM_GPS = 2;

    // РЕЗЕРВ под плату полётника (docs/FC_BOARD.md) — разъёмы
    // разводятся сразу, прошивкой пока не используются.
    constexpr int8_t PIN_AUX1        = 15;  // серво-выход: сброс груза
    constexpr int8_t PIN_AUX2        = 16;  // серво-выход: закрылки (через Y-кабель)
    constexpr int8_t PIN_AUX3        = 47;  // любой цифровой, питание 5V логики (не сервы)
    constexpr int8_t PIN_BUZZER      = 38;  // пищалка через транзистор
    constexpr int8_t PIN_LIGHT       = 21;  // ключ Si2302: огни / фара / электромагнит
    constexpr int8_t PIN_VBAT_ADC    = 8;   // АЦП1: батарея через делитель 56k/10k
    constexpr int8_t PIN_CURRENT_ADC = 3;   // АЦП1: датчик тока через делитель 10k/15k
    constexpr int8_t PIN_TELEM_TX    = 9;   // радиомодем / iBUS-SENS
    constexpr int8_t PIN_TELEM_RX    = 10;
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

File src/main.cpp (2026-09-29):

// ============================================================
// AEROS-001 FLIGHT CONTROLLER — ESP32-S3
//
// Composition root: создаёт все объекты, связывает их и крутит
// полётный цикл. Логики полёта здесь нет — только сборка.
//
// RC-пульт -> приёмник -> iBUS (UART) -> IBusReceiver
//   -> FlightController: ArmingManager / ControlMixer (+ закрылки)
//      / Autopilot (коррекции и газ режима) / ThrottleManager
//   -> FlightOutputs -> сервы и ESC
//
// Потеря связи (нет кадров >500 мс или failsafe-значение газа от
// приёмника) — абсолютный приоритет: мотор в ноль, рули в нейтраль.
// ARM — тумблер SwA при газе внизу. Режим автопилота — SwC (CH7).
//
// Чёрный ящик (BlackBox) пишет полёт во флеш: с ARM и газа до
// посадки — все датчики, стики, выходы, решения автопилота.
//
// Задачи FreeRTOS:
//   ядро 1 — loop(): полётный цикл с фиксированным периодом
//            Config::LOOP_PERIOD_MS (vTaskDelayUntil);
//   ядро 0 — Wi-Fi, веб-дашборд (WebDebugServer), OLED (OledDisplay),
//            запись чёрного ящика во флеш (сразу после каждого такта).
// ============================================================

#include <Arduino.h>

#include "autopilot/Autopilot.h"
#include "autopilot/PilotSwitches.h"
#include "config/Config.h"
#include "control/ArmingManager.h"
#include "control/ControlMixer.h"
#include "control/FlightController.h"
#include "control/FlightOutputs.h"
#include "control/ThrottleManager.h"
#include "hal/esp32/Esp32Board.h"
#include "hal/esp32/Esp32FlashPartition.h"
#include "rc/IBusReceiver.h"
#include "sensors/SensorInterface.h"
#include "sensors/SensorSelection.h"
#include "sensors/airspeed/AirspeedSensor.h"
#include "telemetry/BlackBox.h"
#include "telemetry/BlackBoxStorage.h"
#include "telemetry/DebugConsole.h"
#include "telemetry/DebugLogger.h"
#include "telemetry/LoopStats.h"
#include "telemetry/OledDisplay.h"
#include "telemetry/WebDebugServer.h"


// ------------------------------------------------------------
// Железо. Плата — единственная точка входа в MCU (hal/IBoard.h).
// ------------------------------------------------------------

Esp32Board board;


// ------------------------------------------------------------
// Датчики. Какой чип и на какой шине — sensors/SensorSelection.h.
// Не ответил — isAvailable() == false, автопилот не даёт коррекций.
// ------------------------------------------------------------

auto imuDevice = SELECTED_IMU_DEVICE(board);
SelectedImu imuSensor(imuDevice);

auto baroDevice = SELECTED_BARO_DEVICE(board);
SelectedBaro baroSensor(baroDevice);

#if SENSOR_MAG != SENSOR_MAG_NONE
auto magDevice = SELECTED_MAG_DEVICE(board);
SelectedMag magSensor(magDevice);
MagnetometerSensor* const magnetometer = &magSensor;
#else
MagnetometerSensor* const magnetometer = nullptr;
#endif

#if SENSOR_GPS != SENSOR_GPS_NONE
SelectedGps gpsSensor(board.gpsUart());
GpsSensor* const gpsReceiver = &gpsSensor;
#else
GpsSensor* const gpsReceiver = nullptr;
#endif

// Самодельная трубка Пито: барометр в трубке (полное давление) +
// основной барометр в фюзеляже (статика).
#if SENSOR_AIRSPEED != SENSOR_AIRSPEED_NONE
auto pitotDevice = SELECTED_PITOT_DEVICE(board);
SelectedPitotBaro pitotBaro(pitotDevice, "PITOT-BMP581");
PitotDualBaroAirspeed pitotSensor(pitotBaro, baroSensor);
AirspeedSensor* const airspeedSensor = &pitotSensor;
#else
AirspeedSensor* const airspeedSensor = nullptr;
#endif


// ------------------------------------------------------------
// Управление полётом.
// ------------------------------------------------------------

IBusReceiver ibusReceiver(board.rcUart());
ControlMixer controlMixer;
ThrottleManager throttleManager;
FlightOutputs flightOutputs(board);

Autopilot autopilot(&imuSensor, &baroSensor, magnetometer, gpsReceiver, airspeedSensor);
PilotSwitches pilotSwitches(&autopilot);   // тумблеры и крутилки — config/Controls.h
ArmingManager armingManager(&autopilot);

FlightController flightController(
    ibusReceiver,
    controlMixer,
    throttleManager,
    armingManager,
    flightOutputs,
    &autopilot,
    &pilotSwitches
);


// ------------------------------------------------------------
// Отладка и телеметрия.
// ------------------------------------------------------------

LoopStats loopStats;

// Раздел "blackbox" — partitions_blackbox.csv; на платах без него
// чёрный ящик просто выключен.
Esp32FlashPartition blackBoxFlash("blackbox");
BlackBoxStorage blackBoxStorage(blackBoxFlash);
BlackBox blackBox(flightController, autopilot, loopStats, blackBoxStorage, &pilotSwitches);

DebugLogger debugLogger(flightController, &autopilot, &loopStats);
DebugConsole debugConsole(flightController, flightOutputs, autopilot, debugLogger, &board, &blackBox);
WebDebugServer webDebugServer(flightController, &autopilot);
OledDisplay oledDisplay(flightController, &autopilot, loopStats);


static void printBanner()
{
    Serial.println();
    Serial.println("=================================");
    Serial.println(" AEROS-001 FLIGHT CONTROLLER");
    Serial.println(" ESP32-S3 / OOP ARCHITECTURE");
    Serial.println("=================================");
    Serial.println();
}

// Датчики: опознать, откалибровать те, что ответили. Калибровка
// гироскопа держит самолёт неподвижным ~2 с и заодно проверяет
// установку IMU (предполётная проверка) — включать неподвижно; ровно —
// только пока установка не откалибрована командой 'o'.
static void setupSensors()
{
    if (imuSensor.begin())
    {
        imuSensor.calibrate();
    }

    if (baroSensor.begin())
    {
        baroSensor.calibrateAltitude();
    }

#if SENSOR_MAG != SENSOR_MAG_NONE
    // Калибровка компаса хранится в NVS (пересчитать — 'm' в консоли).
    // Первый отсчёт задаёт начальный курс вместо произвольного 0 —
    // дальше рысканье ведёт гироскоп.
    if (magSensor.begin())
    {
        delay(25);
        magSensor.update();
        imuSensor.setYaw(magSensor.getMagData().headingDegrees);
    }
#endif

#if SENSOR_GPS != SENSOR_GPS_NONE
    gpsSensor.begin();
#endif

#if SENSOR_AIRSPEED != SENSOR_AIRSPEED_NONE
    // Ноль трубки набирается ~1 с в полётном цикле — самолёт стоит,
    // трубка накрыта или развёрнута по ветру.
    pitotSensor.begin();
#endif

    autopilot.begin();
}
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

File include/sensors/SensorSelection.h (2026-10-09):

#pragma once

// ============================================================
// 🔧 ВЫБОР ДАТЧИКОВ ПРОЕКТА
//
// Единственное место, которое нужно менять, чтобы сменить
// физический датчик. Проще всего — одной строкой выбрать готовый
// набор (SENSOR_KIT ниже); можно и каждый датчик по отдельности.
// main.cpp работает через SelectedImu/SelectedBaro/SelectedMag/
// SelectedGps/SelectedPitotBaro и не знает, какой класс за ними стоит.
//
// Для каждого датчика здесь же задано, на какой шине он висит:
// SELECTED_*_DEVICE(board) создаёт регистровое устройство
// (I2cRegisterDevice с адресом или SpiRegisterDevice с CS-пином,
// см. hal/RegisterDevice.h), которое main.cpp передаёт драйверу.
// Драйверы шины не различают — один и тот же BMP581_Sensor
// работает и по I2C, и по SPI.
//
// ПОДДЕРЖИВАЕМЫЕ ДАТЧИКИ:
//   IMU (гироскоп + акселерометр):
//     • MPU6050 / MPU6500 (GY-521) — I2C 0x68; чип по WHO_AM_I
//     • ICM42688 ("601N1")        — SPI, CS = PIN_SPI_CS_IMU
//     • LSM6DSV / 16X / 32X       — I2C 0x6A или 0x6B (сам находит), или SPI
//     • ICM-45686                 — I2C 0x68 или 0x69 (сам находит), или SPI
//   Барометр:
//     • BMP388                    — I2C 0x76 или SPI
//     • BME280 / BMP280           — I2C 0x76
//     • SPL06-001                 — I2C 0x76 или 0x77 (сам находит), или SPI
//     • BMP581                    — I2C 0x46 (0x47 — если нет трубки Пито), или SPI
//   Магнитометр:
//     • QMC5883P (GY-273)         — I2C 0x2C
//     • QMC5883L                  — I2C 0x0D
//     • QMC6309                   — I2C 0x7C (модули с LSM6DSV / ICM-45686)
//     • нет
//   Воздушная скорость:
//     • самодельная трубка Пито: BMP581 в трубке (I2C 0x47, SDO = VDD)
//       + основной барометр в фюзеляже как статика
//       (sensors/airspeed/PitotDualBaroAirspeed.h)
//     • нет
//   GPS:
//     • u-blox M10 (UBX)           — UART
//     • нет
// ============================================================

// Нужны тем, кто раскрывает SELECTED_*_DEVICE(board): макросы
// ссылаются на I2cRegisterDevice/SpiRegisterDevice и пины Config.
#include "config/Config.h"          // IWYU pragma: export
#include "hal/RegisterDevice.h"     // IWYU pragma: export

#define SENSOR_IMU_MPU6050       1
#define SENSOR_IMU_ICM42688      2   // SPI
#define SENSOR_IMU_LSM6DSV       3   // I2C
#define SENSOR_IMU_LSM6DSV_SPI   4
#define SENSOR_IMU_ICM45686      5   // I2C
#define SENSOR_IMU_ICM45686_SPI  6

#define SENSOR_BARO_BME280      1
#define SENSOR_BARO_BMP388      2   // SPI
#define SENSOR_BARO_BMP388_I2C  3
#define SENSOR_BARO_SPL06       4   // I2C
#define SENSOR_BARO_SPL06_SPI   5
#define SENSOR_BARO_BMP581      6   // I2C
#define SENSOR_BARO_BMP581_SPI  7

#define SENSOR_MAG_NONE      0
#define SENSOR_MAG_QMC5883P  1
#define SENSOR_MAG_QMC5883L  2
#define SENSOR_MAG_QMC6309   3

#define SENSOR_AIRSPEED_NONE          0
#define SENSOR_AIRSPEED_PITOT_BMP581  1

#define SENSOR_GPS_NONE      0
#define SENSOR_GPS_UBLOX_M10 1

// Готовые наборы: SENSOR_KIT задаёт все датчики разом.
#define SENSOR_KIT_CUSTOM          0   // каждый датчик — своей строкой ниже
#define SENSOR_KIT_BENCH_GY521     1   // стенд: GY-521 (MPU6500), BMP581 I2C, GY-273 (QMC5883P)
#define SENSOR_KIT_LSM6DSV_PITOT   2   // LSM6DSV+QMC6309, SPL06 в фюзеляже, BMP581 в трубке Пито, GPS
#define SENSOR_KIT_ICM45686_PITOT  3   // ICM-45686+QMC6309, SPL06, BMP581 в трубке, GPS


// --------------------------------------------------------
// АКТИВНЫЙ ВЫБОР — одна строка SENSOR_KIT...
//
// Любую строку можно переопределить флагом сборки без правки файла,
// например build_flags = -D SENSOR_KIT=SENSOR_KIT_LSM6DSV_PITOT.
// --------------------------------------------------------

#ifndef SENSOR_KIT
#define SENSOR_KIT SENSOR_KIT_BENCH_GY521
#endif

#if SENSOR_KIT == SENSOR_KIT_BENCH_GY521
    #define KIT_IMU      SENSOR_IMU_MPU6050
    #define KIT_BARO     SENSOR_BARO_BMP581
    #define KIT_MAG      SENSOR_MAG_QMC5883P
    #define KIT_AIRSPEED SENSOR_AIRSPEED_NONE
    #define KIT_GPS      SENSOR_GPS_NONE
#elif SENSOR_KIT == SENSOR_KIT_LSM6DSV_PITOT
    #define KIT_IMU      SENSOR_IMU_LSM6DSV
    #define KIT_BARO     SENSOR_BARO_SPL06
    #define KIT_MAG      SENSOR_MAG_QMC6309
    #define KIT_AIRSPEED SENSOR_AIRSPEED_PITOT_BMP581
    #define KIT_GPS      SENSOR_GPS_UBLOX_M10
#elif SENSOR_KIT == SENSOR_KIT_ICM45686_PITOT
    #define KIT_IMU      SENSOR_IMU_ICM45686
    #define KIT_BARO     SENSOR_BARO_SPL06
    #define KIT_MAG      SENSOR_MAG_QMC6309
    #define KIT_AIRSPEED SENSOR_AIRSPEED_PITOT_BMP581
    #define KIT_GPS      SENSOR_GPS_UBLOX_M10
#elif SENSOR_KIT != SENSOR_KIT_CUSTOM
    #error "SensorSelection.h: неизвестный SENSOR_KIT"
#endif

// ...или каждый датчик отдельно (SENSOR_KIT_CUSTOM или поверх набора).

#ifndef SENSOR_IMU
#define SENSOR_IMU  KIT_IMU
#endif

#ifndef SENSOR_BARO
#define SENSOR_BARO KIT_BARO
#endif

#ifndef SENSOR_MAG
#define SENSOR_MAG  KIT_MAG
#endif

#ifndef SENSOR_AIRSPEED
#define SENSOR_AIRSPEED KIT_AIRSPEED
#endif

#ifndef SENSOR_GPS
#define SENSOR_GPS  KIT_GPS
#endif


// ============================================================
// РАЗРЕШЕНИЕ В КОНКРЕТНЫЕ ТИПЫ (менять не нужно, кроме адресов/пинов)
// ============================================================

#if SENSOR_IMU == SENSOR_IMU_MPU6050
    #include "sensors/imu/MPU6050_Sensor.h"
    using SelectedImu = MPU6050_Sensor;
    #define SELECTED_IMU_DEVICE(board) I2cRegisterDevice((board).i2c(), 0x68)
#elif SENSOR_IMU == SENSOR_IMU_ICM42688
    #include "sensors/imu/ICM42688_Sensor.h"
    using SelectedImu = ICM42688_Sensor;
    #define SELECTED_IMU_DEVICE(board) ICM42688_Sensor::spiDevice((board).spi(), Config::PIN_SPI_CS_IMU)
#elif SENSOR_IMU == SENSOR_IMU_LSM6DSV
    #include "sensors/imu/LSM6DSV_Sensor.h"
    using SelectedImu = LSM6DSV_Sensor;
    #define SELECTED_IMU_DEVICE(board) I2cRegisterDevice((board).i2c(), LSM6DSV_Sensor::DEFAULT_ADDRESS, LSM6DSV_Sensor::ALTERNATE_ADDRESS)
#elif SENSOR_IMU == SENSOR_IMU_LSM6DSV_SPI
    #include "sensors/imu/LSM6DSV_Sensor.h"
    using SelectedImu = LSM6DSV_Sensor;
    #define SELECTED_IMU_DEVICE(board) LSM6DSV_Sensor::spiDevice((board).spi(), Config::PIN_SPI_CS_IMU)
#elif SENSOR_IMU == SENSOR_IMU_ICM45686
    #include "sensors/imu/ICM45686_Sensor.h"
    using SelectedImu = ICM45686_Sensor;
    #define SELECTED_IMU_DEVICE(board) I2cRegisterDevice((board).i2c(), ICM45686_Sensor::DEFAULT_ADDRESS, ICM45686_Sensor::ALTERNATE_ADDRESS)
#elif SENSOR_IMU == SENSOR_IMU_ICM45686_SPI
    #include "sensors/imu/ICM45686_Sensor.h"
    using SelectedImu = ICM45686_Sensor;
    #define SELECTED_IMU_DEVICE(board) ICM45686_Sensor::spiDevice((board).spi(), Config::PIN_SPI_CS_IMU)
#else
    #error "SensorSelection.h: не задан SENSOR_IMU"
#endif
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

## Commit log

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2026-09-05 Refactor main.cpp to replace PPM with IBUS configuration and update aileron handling
    [main.cpp]
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2026-09-05 Fix aileron right output calculation by adjusting the PWM_CENTER offset
    [main.cpp]
2026-09-09 Implement new feature for user authentication and improve error handling
    [main.cpp]
2026-09-09 Add core flight control classes and configuration
    - Introduced ArmingManager to manage arming state based on throttle and receiver status.
    - Added Channels for logical mapping of RC channels.
    - Created Config for centralized configuration of constants and parameters.
    - Implemented ControlMixer for aerodynamic logic, calculating outputs for ailerons and elevator.
    - Defined FlightOutputState to represent the desired outputs for servos.
    - Developed FlightOutputs to handle PWM signals for servos and manage failsafe states.
    - Created IBusReceiver for handling iBUS frames and updating RC channel states.
    - Introduced RcChannelState to represent the state of RC channels.
    - Added RcInput utilities fo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
    [Config.h, ControlMixer.h, FlightOutputState.h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]
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2026-09-09 small bugfix (add include)
    [FlightOutputState.h]
2026-09-15 Fix uninitialized Autopilot corrections; add named feature-channel slots
    rollCorrection/pitchCorrection/throttleCorrection were left
    uninitialized until the first real mode change, so FlightController
    could add garbage floats to aileron/elevator outputs while armed.
    Also trims the comment banners down to what's actually non-obvious.
    Channels.h gains Channels::FEATURE_SLOTS - the four aux channels
    FeatureManager is meant to use - so the mapping is defined in one
    place instead of being reconstructed with channel+7 arithmetic.
    [Autopilot.h]
2026-09-15 Fix FeatureManager channel off-by-one/boost conflict; report per-servo attach status
    FeatureManager read rcState.get(ch+7) for ch=0..3, i.e. indices
    7,8,9,10 - index 10 is out of range (valid channels are 0-9) and
    always read back as PWM_CENTER, so its 4th slot (FEATURE_MANUAL by
    default) was permanently "active". Index 7 also collided with
    Channels::BOOST, which ThrottleManager already reads for the boost
    switch. Now uses the four channels actually free for this
    (Channels::FEATURE_SLOTS - CH6, CH7, CH9, CH10) and the public API
    takes a slot index instead of reconstructing a channel number.
    FlightOutputs now records attach() per servo/ESC instead of one
    combined bool, and prints per-channel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
    [BME280_Sensor.h]
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2026-09-15 Distinguish missing vs unresponsive sensors in Autopilot status; wire DebugLogger to it
    Autopilot::printStatus() used to check only whether the sensor
    pointer was non-null, so a physically disconnected/unresponsive
    sensor still printed roll/pitch/altitude as if it were real data
    (silently zeroed). Now reports imu=NOT_ATTACHED / NO_RESPONSE (same
    for baro) instead of fabricating readings.
    DebugLogger takes optional Autopilot*/FeatureManager* pointers and
    prints their status lines alongside the existing RC/output line, so
    the same graceful-degradation info shows up over Serial once these
    are wired into main.cpp.
    FlightController.h comments trimmed to the one thing that actually
    matters here: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
    [Autopilot.h]
2026-09-15 Rewrite WebDebugServer around one honest /api/status endpoint
    The old /api/sensors built its JSON with conditional field blocks
    (autopilot present, imuSensor present, baroSensor present are each
    optional) but always terminated the string the same way, so several
    combinations produced trailing commas or an empty "{}" - invalid
    JSON the dashboard silently swallowed in a try/catch, which is
    exactly the "nothing shown when a sensor is missing" behavior this
    was meant to fix.
    /api/status now always emits the same shape with explicit
    attached/available booleans for every output servo and every
    sensor, so the dashboard can show "NOT WIRED" vs "NOT RESPONDING"
    vs a real reading instead of guessing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
    [Autopilot.h]
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2026-09-15 Fix RX failsafe timeout: was 100ms, every doc and the debugging guide says 500ms
    Found this while bench-testing on real hardware after wiring
    everything into main.cpp: the receiver was reported as LOST
    immediately, even though it should tolerate several missed 10ms
    iBUS frames. Config::RX_TIMEOUT_US was 100000 (100us... written as
    100ms worth of micros, i.e. 100000us = 100ms) while
    DEBUGGING_GUIDE.md's own troubleshooting checklist says "Проверить
    Config::RX_TIMEOUT_US (должно быть 500000)", and
    CHANNELS_REFERENCE.md/SIGNAL_FLOW_GUIDE.md/AUTOPILOT_IMPLEMENTATION_SUMMARY.md
    all describe 500ms failsafe behavior. 100ms is only 10 frames at
    the receiver's ~10ms frame rate - on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
    [Config.h]
2026-09-15 Make board pinout swappable: platformio.ini env picks Config.h's pin set
    Groundwork for the planned move to a custom flight-controller board
    (ESP32-S3 primary, ESP32-C3 kept as reserve) while still being able
    to bench-test on a plain 38-pin ESP32 devkit. Switching board is now
    one flag: `pio run -e esp32-c3` / `-e esp32-s3` / `-e esp32-dev`
    (default_envs stays esp32-c3, matching what's actually flashed and
    tested). Each env defines exactly one -D BOARD_ESP32_* macro, and
    Config.h picks that board's pin block from it - to add a board,
    copy one #elif and adjust pin numbers.
    Checked actual pins_arduino.h in the installed framework package for
    each chip variant rather than assuming: esp32c3's d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
    [BME280_Sensor.h, Config.h]
2026-09-15 Apply autopilot throttle correction to the mixer output
    Autopilot::getThrottleCorrection() is computed by ALT_HOLD and
    AUTO_TAKEOFF but FlightController::update() never added it to
    output.throttle - only the roll/pitch corrections were applied.
    Found this while fact-checking docs/DEVELOPER_GUIDE.md against the
    actual source: a docs-writing agent caught the mismatch between what
    Autopilot.h computes and what FlightController.h actually uses.
    The correction is a percentage (-100..100, matching the ALT_HOLD PID
    limits and AUTO_TAKEOFF's autoTakeoffThrottle-50 baseline), not
    microseconds like the roll/pitch corrections above it, so it's
    scaled onto the PWM_MIN..PWM_MAX span before being added,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
2026-09-17 Fix GPS UART on ESP32-C3, add QMC5883L driver, fix stale GPS staleness check
    Esp32Board hard-coded the GPS HardwareSerial to UART2, which doesn't
    physically exist on ESP32-C3 (only UART0/UART1, and UART1 is already
    iBUS). Added a per-board Config::UART_NUM_GPS constant (C3 = 0, free
    there since Serial runs over USB-CDC; S3/classic = 2, unchanged) and
    wired it into Esp32Board's constructor instead of the hard-coded 2.
    Added QMC5883L_Sensor.h as a proper sibling to QMC5883P_Sensor.h.
    QMC5883L is the far more common chip on "GY-273" boards, and its
    address (0x0D) and register layout are verified against its datasheet
    (QMC5883P_Sensor.h remains an unverified placeholder for the rarer
    variant, n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
    [Config.h, SensorSelection.h, UbloxM10_Gps.h]
2026-09-24 Bring up ESP32-S3 N16R8 bench: sensors, safety fixes, LEDC outputs, OLED
    Board and runtime
    - esp32-s3 env for N16R8 (qio_opi PSRAM, 16 MB flash), now the default
    - Serial on UART0 ("COM" port, CH343) with a 4 KB TX buffer
    - Fixed-rate 500 Hz control loop (vTaskDelayUntil) with loop stats
    - Web server moved to its own task on core 0; setmode/setpid go through
    a spinlock-protected mailbox applied by the flight loop
    - SSD1306 OLED status screen on a second I2C bus (Wire1, own task)
    - Serial console: h/s/i/m/p (help, sensor status, IMU and compass
    calibration, output pulse self-test)
    Safety
    - FS-iA6B keeps sending iBUS frames when the transmitter is lost, so the
    frame timeout never fired: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
    [Autopilot.h, BME280_Sensor.h, BMP388_Sensor.h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]
2026-09-24 Add rudder output and proper flaperon flaps on SwB
    - Rudder (CH4, left stick) on its own output: GPIO18 on ESP32-S3,
    GPIO25 on classic ESP32, not available on ESP32-C3 (PIN_RUDDER = -1,
    the output is simply not attached). The nose/tail wheel shares the
    rudder servo. RUDDER_REVERSED, FAILSAFE_RUDDER in Config.h.
    - Flaps move to switch SwB (CH6): both ailerons go down together by
    FLAPS_DEPLOYED_US (220 us, ~20 deg of servo) with a 1 s slew, roll
    from sticks and autopilot is applied differentially on top. Switch
    threshold 1750 so flaps never deploy before the first iBUS frame
    (all channels default to 1500). VrA (CH9) is free now.
    - Rudder and flaps shown on the OLED, in the debug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
    [Config.h, ControlMixer.h, FlightOutputState.h]
2026-09-24 Refactor into layered modules, add failsafe glide, fix sensor bugs
    Structure
    - include/ split into config/, hal/, rc/, control/, autopilot/,
    sensors/{imu,baro,mag,gps}/, telemetry/; every header includes what
    it uses (paths from include/), include.h removed
    - hal/RegisterDevice.h: IRegisterDevice with I2C and SPI adapters;
    sensor drivers take an IRegisterDevice& and no longer care which bus
    they are on (bus, address, CS are chosen in SensorSelection.h)
    - ImuSensorBase + AttitudeEstimator, BarometerBase, MagnetometerBase
    hold the shared logic (calibration, axis rotation, aviation signs,
    complementary filter, altitude/climb, NVS compass calibration, bus
    error accounting); chip dr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
    [Autopilot.h, BME280_Sensor.h, BMP388_Sensor.h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]
2026-09-24 Add adaptive feedback control stub with on-board closed-loop simulation
    The stub lives in include/autopilot/feedback/ and is NOT wired into
    FlightController, Autopilot or main.cpp yet (no airframe for flight
    tests). It closes the loop on the aircraft's actual response instead of
    fixed PID gains:
    - ControlEffectivenessEstimator: per-axis RLS of angular accel =
    b*u(t-delay) + a*rate + c, normalized to reference speed (b ~ V^2),
    interval-averaged data with a shared prefilter on both sides
    - AdaptiveRateController: angle -> rate -> accel -> deflection through
    the learned model, rate integral kept in deg/s ("not enough - add more")
    - ControlDirectionGuard: auto-inversion on confident rever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
    [AdaptiveRateController.h, ControlEffectivenessEstimator.h, FeedbackConfig.h]
2026-09-24 Replace C++17 inline static member in OledDisplay
    The Arduino core builds with gnu++11, so `static inline` data members
    only worked as a GCC extension and produced a warning on every board.
    A function-local static gives the same single instance in C++11.
2026-09-24 Add bench photos to README, document feedback stub, fix stale paths
    - docs/images: test bench, thrust test and web dashboard screenshots
    (photos downscaled to 1600 px, metadata stripped)
    - README: photo tables, feedback stub summary, updated tree and roadmap;
    dashboard shows 5 outputs, not 4
    - DEVELOPER_GUIDE: feedback section (design, modules, simulation,
    wiring plan), airspeed sensor, test instructions, known limitations
    - ROADMAP: phase 2.5 for feedback control; file paths after the
    layered refactor (include/config/Config.h, sensors/<category>/)
2026-09-24 Calibrate IMU mounting on the ground instead of flipping axes in flight
    IMU mounting (live firmware):
    - ImuOrientation: chip->body rotation matrix, either from
    IMU_ROTATION_CW_DEG (legacy, chip up) or from three static poses
    (level, nose up, right wing down) so the board can be mounted in any
    orientation; pose 3 cross-checks pose 2 and pilot mistakes (nose down,
    wrong wing, wrong axis, too little tilt) are rejected; stored in NVS
    - console 'o' runs the 3-pose procedure; each pose is captured
    automatically after ~1 s of stillness
    - power-on preflight check in ImuSensorBase::calibrate(): gyro noise
    (plane moved), 1 g at rest, "up" matches the stored mounting (board
    moved or flipp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
    [AdaptiveRateController.h, Autopilot.h, Config.h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]
2026-09-24 Channel-based debug log with text menu, RC joystick tool, FC board plan
    Debug output (live firmware):
    - DebugLogger prints per-channel lines (STAT, RC, OUT, ATT, AP, ALT,
    MAG, GPS, IMU, SYS), each with its own deadband and mode: off / on
    change / periodic (0.2-2 s); a changing channel no longer drags the
    whole frame into the log
    - DebugConsole: text menus ('h' main, 'l' log channels), space pauses
    the log, the log stays quiet while a menu is open and reprints after
    - LogSettings persist in NVS, written on menu close and only when
    disarmed: an NVS write was measured to stall the flight loop ~0.4 s
    - SYS shows the worst loop time over the 10 s interval
    (LoopStats::takePeakUs), not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
    [Autopilot.h, Config.h, FeedbackConfig.h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]
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2026-09-25 Add architecture overview and per-class reference documentation
    docs/ARCHITECTURE.md describes layers and dependency rules, the object
    graph built in main.cpp, class hierarchies, FreeRTOS tasks and data
    sharing, the control-loop sequence, state machines (ARM, autopilot
    modes, takeoff/landing), sensor fault handling and extension points.
    docs/reference/ documents every class, struct, enum and namespace layer
    by layer: public API, fields, formulas and invariants.
    Also fix stale paths in DEVELOPER_GUIDE (Channels.h, WebDebugServer.h),
    replace its console section, which still described the pre-menu log
    format, and link the new documents from README.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
2026-09-25 Fix compiler, cppcheck and clang-tidy findings; clean up includes
    Lint profile: GCC -Wall -Wextra -Wshadow on all three boards,
    cppcheck via pio check, clang-tidy with the new .clang-tidy (run on
    the host with the native fakes). All three now report zero findings
    in include/ and src/.
    Bugs found along the way:
    - WebDebugServer::extractJsonNumber only accepted "key":value with no
    spaces, so the documented {"mode": 1} was rejected and setpid with
    spaces silently kept the old gains; numbers in exponent form
    (JSON.stringify(1e-7)) were read as their mantissa. Whitespace and
    full JSON number syntax are now accepted.
    - MagnetometerBase::calibrate() with no successful read stored
    INT16_M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
    [AdaptiveRateController.h, Autopilot.h, BME280_Sensor.h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]
2026-09-25 Add native test suites for every module, 99% line coverage
    182 new host tests in ten suites under test/native/, plus the two
    existing board suites now running on the host too (197 in total):
    HAL (I2C/SPI helpers, register devices, ESP32 bus/UART/LEDC wrappers,
    Esp32Board), RC (iBUS parsing, failsafe, timeouts across micros()
    overflow, resync), control (flaps, mixer signs and reversal, ARM state
    machine and sensor checks, output table and pulse self-test),
    autopilot (PID, every mode, takeoff program, ALT_HOLD, failsafe
    glide, CH7 selector), FlightController priorities, IMU drivers
    (detection, axes and aviation signs, bus errors, gyro and three-pose
    mounting calibration, preflight checks, NVS)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
    [gcovr.cfg]
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2026-09-27 Add LSM6DSV, ICM-45686, QMC6309, SPL06, BMP581 drivers and a dual-baro pitot
    New sensors for the next hardware kits, each written against the
    official/reference register maps (ST lsm6dsv-pid, TDK ICM45686 driver
    and Zephyr, qmc6309 crate, ArduPilot SPL06 and Invensensev3 drivers,
    Bosch BMP5_SensorAPI):
    - LSM6DSV/16X/32X: detects the 32X variant from CTRL8 and uses its own
    +-16g code (the 16X code would give +-32g and halve the readings).
    - ICM-45686: little-endian UI registers, UI low-pass filters set through
    the IREG indirect registers with read-modify-write.
    - QMC6309: waits for NVM reload after soft reset, 4096 LSB/G at +-8 G.
    - SPL06-001: 18 packed coefficients with sign extension,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
    [Config.h, PitotDualBaroAirspeed.h]
2026-09-27 Add autopilot modes, one-line switch bindings, closed-loop sims and full STM32H743 port
    Autopilot:
    - 12 modes: MANUAL, STABILIZE (angle mode), ALT_HOLD, ACRO, CRUISE,
    LOITER, RTH, AUTO_TAKEOFF, LAUNCH (hand launch), AUTO_LAND, SOARING
    (thermal detection with total-energy vario), RESCUE.
    - Navigation (course/orbit guidance, home, geofence), altitude/airspeed
    control with the pitot tube, stall protection, turn coordination,
    auto trim (saved only after DISARM on the ground), failsafe RTH/glide.
    - config/Controls.h: every switch or knob is one line
    (Bind::modes/mode/feature/knob), checked by static_assert. Features:
    flaps, airbrake, auto trim, motor kill, beeper, payload drop,
    geof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
    [AltitudeSpeedController.h, Autopilot.h, Config.h]
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2026-09-27 Rewrite the README with visuals; review pass 2 fixes
    README: banner, badges, a replay of the link-loss return home rendered
    from the closed-loop simulation, plots of every autopilot mode
    (tools/plot_sim.py), a fresh dashboard screenshot rendered from the
    firmware page, board and sensor tables, honest status and roadmap. The
    roadmap and guides now say plainly that only manual flight has flown so
    far; the autopilot is bench-, test- and simulation-verified.
    Review pass 2:
    - Course source switches between GPS and compass with 1 m/s of
    hysteresis, so a strong headwind no longer resets the target course
    every few ticks.
    - Dashboard: GPS coordinates with 6 decimals and integer fix/satellite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
    [Autopilot.h]
2026-09-27 Simulate sensor failures in flight; add the header splitter tool
    Review pass 3:
    - New closed-loop scenario: in CRUISE the GPS drops out (course falls
    back to the compass), the pitot hoses get swapped (the tube reports a
    fault, throttle falls back to the cruise knob), the barometer goes
    silent and finally the IMU fails (surfaces go straight to the sticks).
    The plane keeps flying: bank under 35 degrees, never below stall speed
    or 30 m.
    - tools/split_headers.py: libclang-based generator of the .h/.cpp layout
    for the parallel feature/split-headers branch, so that branch is
    regenerated from this one instead of drifting by hand.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
2026-09-27 Fix test_ignore patterns; link EEPROM for STM32 board tests
    PlatformIO splits multi-value options on newlines or ', ', so
    'native/* native_stm32/*' was one pattern that matched nothing and
    pio test -e esp32-s3 would try to build the PC-only suites. The STM32
    board test test_imu_orientation reaches <EEPROM.h> only through
    <Preferences.h> behind a -I flag, which the dependency finder does not
    follow — list the core library explicitly.
    Test counts in the docs: 330 (the in-flight sensor failure scenario).
    Claude-Session: https://claude.ai/code/session_019nJYcKCvZHTe259b1RcrUH
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2026-09-29 Take rudder travel from Config in the control tests
    Two mixer tests hard-coded 500 us of rudder throw and broke when
    RUDDER_MAX_US went down to 300.
2026-09-29 Add the flight black box: record every flight to on-board flash
    The ESP32-S3 N16R8 gets a 13.9 MB "blackbox" partition
    (partitions_blackbox.csv; nvs stays in place, so calibrations survive).
    BlackBox records from ARM + throttle (with 10 s of pre-roll) until 10 s
    after DISARM, or until the armed plane has sat still with the motor off
    for 30 s; a crash reset (panic, watchdog, brownout) starts a recording
    at boot. Link loss, motor off and gliding never stop it.
    What is logged: IMU at the loop rate (500 Hz) with the loop work time;
    attitude, autopilot targets, sticks, commands, all seven outputs and
    the roll/pitch PID terms at 100 Hz; RC at 50 Hz; every baro, compass,
    GPS and airspeed sample; n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
    [partitions_blackbox.csv]
2026-09-30 Reverse the right aileron servo
    Wing servos are mounted as mirror images of each other, so only one
    side needs AILERON_*_REVERSED flipped for roll and flaperon travel to
    agree on direction. The mixer itself is unchanged — only the physical
    servo-output sign.
    [Config.h]
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2026-10-17 Make the bidirectional BLHeli 80A ESC the main one, with a disarm-only motor reverse
    The ESC output now speaks 3D: throttle stays 1000..2000 = 0..100% inside the
    firmware, and FlightOutputs turns it plus the direction into the ESC pulse
    (EscSignal): 1500 = stop, 1500..2000 forwards, 1500..1000 backwards. DISARM,
    failsafe and MOTOR_KILL therefore output 1500, not full reverse.
    ESC_BIDIRECTIONAL = false keeps an ordinary ESC working.
    Motor reverse is Feature::MOTOR_REVERSE on SwD (RTH moves off the switch,
    one line in Controls.h brings it back). MotorReverse changes direction only
    when disarmed: a flip while armed is ignored until DISARM, and ARM is refused
    for REVERSE_SETTLE_MS (3 s) after a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
2026-10-17 One-line reverse for everything, and a throttle-limit knob
    Reverse: Config.h now has one block where every flag flips exactly one
    thing — each aileron, elevator, rudder, AUX1 (payload), AUX2 (camera),
    MOTOR_REVERSED (motor direction instead of swapping two wires; bidirectional
    ESC only, enforced by static_assert), FLAPS_REVERSED (flaps/airbrake without
    touching roll) and CHANNEL_REVERSED[] for any transmitter channel. CH3 cannot
    be reversed: link loss is detected on the raw throttle before reversal
    (static_assert). New flags are logged in the black box header.
    Knob::THROTTLE_LIMIT: 10..55..100 % on top of THROTTLE_LIMIT_PCT, the allowed
    throttle is stretched over the whole stick travel (a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
2026-10-17 Staged runway takeoff for tail-wheel planes, ground calibration from the transmitter
    AUTO_TAKEOFF is now a TakeoffController that moves by what the plane does,
    not by a timer: CHECK (still, angles match the parking attitude) -> TAIL_UP
    (down elevator, the propwash lifts the tail) -> ROLL (level on the mains) ->
    LIFTOFF (pitch target rises but stays 3 deg below the parking attitude until
    liftoff, so the tail wheel never takes the load) -> CLIMB (+8 deg to 30 m,
    by time without a barometer) -> DONE. The program owns the throttle; the
    stick only starts and aborts. Aborts on the runway: throttle down, link
    loss, IMU failure, roll, heading, nose down, tail not up, no liftoff. The
    attitude runs on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
2026-10-18 Describe the firmware for OpenPlane Studio and report its identity
    tools/opconfig.py describes the firmware as JSON (boards, every Config.h
    parameter with its comment, channels, modes/features/knobs with what
    each needs, sensors and current switch bindings) and writes a plane's
    configuration back into a copy of the sources. The requirements live
    next to the code: @needs/@better tags in AutopilotTypes.h, @board tags
    on the pin blocks, @fixed on protocol constants. `opconfig.py check`
    fails when a tag is missing or when writing the current values would
    change a byte; tools/test_opconfig.py (14 tests) and
    tools/opconfig_build_check.py (all 4 boards build) cover it.
    The console answers STX "id"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
2026-10-18 Stream live state to OpenPlane Studio over the console port
    AppLink sends one JSON line per frame ("@live {...}": arm, mode, link,
    channels, outputs, attitude, sensors, why ARM is refused, ground
    calibration stage, active features, loop rate) while the app keeps
    asking for it with "live" once a second, and goes quiet on its own
    when the app stops. A frame is skipped instead of waited for when the
    port buffer is full, so the flight loop never waits for the PC.
    The console also answers "scan" (I2C devices as JSON, refused while
    armed) and "act X" (the same actions as the menu keys), and
    FlightController::armBlockNow() tells the reason ARM would be refused
    before the pilot flips the switch.
    C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

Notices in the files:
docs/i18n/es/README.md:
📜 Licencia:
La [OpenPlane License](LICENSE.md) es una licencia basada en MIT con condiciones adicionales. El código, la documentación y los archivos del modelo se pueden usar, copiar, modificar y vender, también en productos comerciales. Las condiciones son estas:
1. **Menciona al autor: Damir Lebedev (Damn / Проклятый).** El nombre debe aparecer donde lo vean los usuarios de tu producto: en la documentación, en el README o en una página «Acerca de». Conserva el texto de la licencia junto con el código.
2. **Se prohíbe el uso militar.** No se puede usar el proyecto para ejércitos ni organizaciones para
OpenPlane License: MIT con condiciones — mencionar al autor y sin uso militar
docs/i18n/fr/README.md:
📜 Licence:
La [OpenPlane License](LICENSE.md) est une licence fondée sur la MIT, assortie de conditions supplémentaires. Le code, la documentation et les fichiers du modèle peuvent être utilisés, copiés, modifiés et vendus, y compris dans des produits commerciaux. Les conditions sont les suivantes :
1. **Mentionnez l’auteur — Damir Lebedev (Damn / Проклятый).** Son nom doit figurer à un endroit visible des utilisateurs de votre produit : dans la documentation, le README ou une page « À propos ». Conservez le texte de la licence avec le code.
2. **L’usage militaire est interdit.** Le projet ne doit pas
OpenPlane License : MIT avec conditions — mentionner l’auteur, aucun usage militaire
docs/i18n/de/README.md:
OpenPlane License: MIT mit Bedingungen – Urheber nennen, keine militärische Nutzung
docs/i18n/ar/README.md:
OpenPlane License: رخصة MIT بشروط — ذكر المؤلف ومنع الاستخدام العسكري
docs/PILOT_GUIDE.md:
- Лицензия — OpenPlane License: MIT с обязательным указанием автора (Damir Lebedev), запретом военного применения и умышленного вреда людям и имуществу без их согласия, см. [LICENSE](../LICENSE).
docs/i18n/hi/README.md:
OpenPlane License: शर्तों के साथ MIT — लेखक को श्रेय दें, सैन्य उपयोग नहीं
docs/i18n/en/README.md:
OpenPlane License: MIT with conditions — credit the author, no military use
